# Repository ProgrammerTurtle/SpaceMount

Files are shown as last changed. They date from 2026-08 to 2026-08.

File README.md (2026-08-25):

# SpaceMount

Full_Astrophotography_Mount_2026-Aug-24_03-28-08AM-000_CustomizedView19236172479

**SpaceMount** is an open source astrophotography mount suite consisting of an automatic polar alignment unit, an equatorial mount unit, and a custom carbon fiber guider scope. 

Control is carried out by a Raspberry Pi 4B running [PINS](https://github.com/nitr57/pins) talking to an SKR Pico 3D printer mainboard sporting custom firmware. 

## Structure

SpaceMount sports a high rigidity frame made out of 1/4" lasercut aluminum, aluminum extrusions, and printed parts made of engineering-grade materials. This allows for high load capacity, high rigidity, and high accuracy. All important features to get the perfect shot.

## Drive

Gearbox_-_Lower_Stage_101_2026-Aug-24_03-46-59AM-000_CustomizedView28774878801

Mechanically, it features 3 fully custom high ratio dual stage cycloidal gearboxes powered by high torque Nema 17 stepper motors.
- One Gearbox for Azimuth
- One Gearbox for DEC
- One Gearbox for R. A.
These gearboxes are an 81:1 reduction, outputting 35Nm of torque! This allows for a high load capacity. 

The altitude axis features a custom 200:1 worm-gear-belt-drive system for resisting the toughest of conditions. 

## Polar Alignment



Mounted on the altitude axis is a camera for Polar Alignment. Utilizing Plate Solving running on the Raspberry Pi 4B, it will automatically scan the sky and align your equatorial mount with Earth's pole! No fiddling with alignment for hours. 

## Bill of Materials

The BOM can be found [here](https://docs.google.com/spreadsheets/d/1fLNac8KSqefRcGDmUohNeKdPQae2YU7nyDo7UR2l_qA/edit?usp=sharing) or attached as a .CSV in the repo.

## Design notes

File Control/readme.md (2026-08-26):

| | | |
|---|---|---|
| Top Level | [PINS](https://github.com/nitr57/pins) | Raspberry Pi |
| | | |
| Plate Solving | [ASTAP](https://www.hnsky.org/astap.htm) | Raspberry Pi |
| | | |
| Guiding | [PHD2](https://openphdguiding.org/) | Raspberry Pi |
| | | |
| Mid Level | [INDI Web Manager](https://github.com/knro/indiwebmanager) | Raspberry Pi |
| | | |
| Translation | [Custom Mount Driver](https://github.com/ProgrammerTurtle/SpaceMount/tree/main/Control/drivers) | Raspberry Pi |
| | | |
| Low Level | [Custom SKR Pico Firmware](https://github.com/ProgrammerTurtle/SpaceMount/tree/main/Control/firmware) | SKR Pico |

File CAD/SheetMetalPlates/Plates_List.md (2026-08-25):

## ALL 1/4" ALUMINUM

Polar Mount			

1	Base Arcaswiss Adapter Plate

1	Bottom Main Plate		

1	Side Plate	

1	Side Plate_Threaded	

2	Camera Mount Side Plate	

2	Shaft Plate	

1	Top Mount Plate	

---			
			
Equatorial Mount			

1	Front Plate		

1	Back Plate	

1	Bottom Plate	

2	Vixen Adapter Plate

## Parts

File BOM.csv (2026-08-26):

SpaceMount BOM |  |  | Total Estimated Cost: | $995.92
Item Name | Quantity | Cost | Use | Source | Notes
Polar Mount
Sheet Metal Plates | 9 | $142.00 | Frame | https://www.oshcut.com/ | See Plates_List
87.3mm 2040 Extrusion | 2 | $22.00 | Frame | https://www.aliexpress.us/item/3256802459096306.html? | Covers Both Lengths of 2040 - Buy 400mm and Cut to Size
52.8mm 2040 Extrusion | 2 |  | Frame
87.3mm 4040 Extrusion | 1 | $12.00 | Altitude Shaft | https://www.aliexpress.us/item/3256807986307289.html? | Buy 100mm and Cut to Size
Arcaswiss Mounting Plate and Clamp | 1 | $22.35 | Mounting | https://www.aliexpress.us/item/2251832498884091.html
RU42UUCC0 Bearing | 1 | $28.80 | Azimuth Output | https://www.aliexpress.us/item/3256808596705253.html?
61815 Bearing | 2 | $33.00 | Altitude Turret Bearing | https://www.aliexpress.us/item/3256812188522321.html?
F695 Bearing | 2 | $5.00 | Altitude Gearing Bearing | https://www.aliexpress.us/item/3256808879550935.html?
6811 Bearing | 1 | $15.00 | Azimuth Gearbox Internal Bearing | https://www.aliexpress.us/item/3256812548641570.html
6803 Bearing | 2 | $3.65 | Azimuth Gearbox Internal Bearing | https://www.aliexpress.us/item/3256808633000961.html?
5mm x 100mm Steel Pin | 1 | $11.00 | Altitude Gearing Shaft | https://www.aliexpress.us/item/3256807759794825.html?
5mm x 15mm Steel Pin | 10 | $10.00 | Azimuth Gearbox Internal Pins | https://www.aliexpress.us/item/3256807759794825.html? | Buy 2 packs
15mm M3 Standoff | 12 | $8.00 | Azimuth Gearbox Output Pin Shafts | https://www.aliexpress.us/item/3256803337647492.html? | Buy 2 packs
5mmx8mmx12mm Brass Bushing | 12 | $12.00 | Azimuth Gearbox Ouput Pin Bushings | https://www.aliexpress.us/item/3256810437400585.html? | Buy 2 packs
50t 5mm Bore Worm Gear Set | 1 | $20.50 | Altitude Gearing Gear | https://www.aliexpress.us/item/2255800299678278.html?
40T 5mm Bore 6mm Belt Pulley | 2 | $12.00 | Altitude Gearing Pulleys | https://www.aliexpress.us/item/2251832807875643.html?
450mm Length Closed Loop GT2 6mm Belt | 2 | $15.00 | Altitude Gearing Belts | https://www.aliexpress.us/item/3256812034723597.html?
Angeleyes Small Vixen Clamp | 1 | $34.00 | Altitude External Mounting | https://www.aliexpress.us/item/3256807005155740.html?
M6x10mm Socket Head Bolts | 4 | $3 | Assembly | https://www.aliexpress.us/item/3256802134660814.html
M5x100mm Socket Head Bolts | 7 | $10 | Assembly | https://www.amazon.com/Joamang-M5-0-8-Socket-Stainless-Threaded/dp/B0DPHTLG5H/
M5x10mm Socket Head Bolts | 9 | $2 | Assembly | https://www.aliexpress.us/item/3256802134660814.html
M5x16mm Socket Head Bolts | 36 | $10 | Assembly | https://www.amazon.com/M5-0-8-Socket-Screws-Stainless-Thread/dp/B07PXL8DGH
M5x25mm Socket Head Bolts | 21 | $7 | Assembly | https://www.aliexpress.us/item/3256802134660814.html? | Buy 3 packs
M5x20mm Socket Head Bolts | 2 | $2.50 | Assembly | https://www.aliexpress.us/item/3256802134660814.html?
M5 Heat Set Inserts Long (M5xL6xOD7) | 4 |  | Assembly | https://www.aliexpress.us/item/3256805885174058.html?
M4x75mm Socket Head Bolts | 10 | $7.00 | Assembly | https://www.aliexpress.us/item/3256808167502621.html
M4x16mm Socket Head Bolt | 4 |  | Assembly | https://www.aliexpress.us/item/3256802134660814.html
M4 Hex Locknuts | 10 | $2.00 | Assembly | https://www.aliexpress.us/item/2251832801119212.html?
M3x16mm Countersunk Head Bolts | 12 | $2.50 | Assembly | https://www.aliexpress.us/item/2251832781782755.html?
M3x40mm Socket Head Bolts | 4 |  | Assembly | https://www.aliexpress.us/item/3256802134660814.html
M3x25mm Socket Head Bolts | 6 | $3.50 | Assembly | https://www.aliexpress.us/item/3256802134660814.html
M3x20mm Socket Head Bolts | 6 | $3.20 | Assembly | https://www.aliexpress.us/item/3256802134660814.html
M3x12mm Socket Head Bolts | 4 | $3.00 | Assembly | https://www.aliexpress.us/item/3256802134660814.html
M3 Heat Set Inserts Long (M3xL6xOD4) | 9 |  | Assembly | https://www.aliexpress.us/item/3256805885174058.html?
M2x12mm Socket Head Bolts | 4 | $1.82 | Assembly | https://www.aliexpress.us/item/3256802134660814.html
M2x5mm Socket Head Bolts | 4 | $2 | Assembly | https://www.aliexpress.us/item/3256802134660814.html
5mm Bore Shaft Collar | 1 | $2 | Azimuth Gearbox Cam Shaft Attachment | https://www.aliexpress.us/item/3256810520261418.html?
2004s1 Nema 17 Stepper Motor | 2 | $28 | Drive Motors | https://www.aliexpress.us/item/3256806039037773.html? | Use Any with Decent Torque
Equatorial Mount
Sheet Metal Plates | 5 | $88.00 | Frame | https://www.oshcut.com/
87.3mm 2040 Extrusion | 4 | $22.00 | Frame | https://www.aliexpress.us/item/3256802459096306.html | Buy 400mm and Cut to Size
Angeleyes Small Vixen Clamp | 1 | $34.00 | Altitude External Mounting | https://www.aliexpress.us/item/3256807005155740.html?
Angeleyes 80mm Vixen Rail | 1 | $13.00 | Mounting | https://www.aliexpress.us/item/3256808818951030.html?
5mm x 15mm Steel Pin | 20 | $15.00 | R.A. and Dec Gearbox Internal Pins | https://www.aliexpress.us/item/3256807759794825.html? | Buy 4 packs
15mm M3 Standoff | 24 | $12.00 | R.A and Dec Gearbox Output Pin Shafts | https://www.aliexpress.us/item/3256803337647492.html? | Buy 3 packs
5mmx8mmx12mm Brass Bushing | 24 | $14.00 | R.A. and Dec Gearbox Ouput Pin Bushings | https://www.aliexpress.us/item/3256810437400585.html? | Buy 3 packs
RU42UUCC0 Bearing | 2 | $60.00 | R.A. and Dec Main Bearings | https://www.aliexpress.us/item/3256808596705253.html?
6811 Bearing | 2 | $33.00 | R.A. and Dec Gearbox Internal Bearings | https://www.aliexpress.us/item/3256812548641570.html
6803 Bearing | 4 | $7.80 | R.A. and Dec Gearbox Internal Bearing | https://www.aliexpress.us/item/3256808633000961.html?
M6x12 Socket Head Bolt | 3 | $3.00 | Assembly | https://www.aliexpress.us/item/3256802134660814.html
M6x10 Socket Head Bolt | 4 | $3.00 | Assembly | https://www.aliexpress.us/item/3256802134660814.html
M5x16mm Socket Head Bolt | 16 | $5.00 | Assembly | https://www.aliexpress.us/item/3256802134660814.html | Buy 2 packs
M5x10mm Socket Head Bolt | 6 | $2.00 | Assembly | https://www.aliexpress.us/item/3256802134660814.html
M5 T Nuts | 6 | $6.20 | Assembly | https://www.aliexpress.us/item/2251832618848960.html? | Use extra to attach any mods/additions to the existing extrusions.
M4x75mm Socket Head Bolt | 20 | $11.00 | Assembly | https://www.aliexpress.us/item/3256808167502621.html | Buy 2 packs
M4 Hex Locknuts | 20 | $4.00 | Assembly | https://www.aliexpress.us/item/2251832801119212.html | Buy 2 packs
M3x16mm Countersunk Head Bolts | 24 |  | Assembly | https://www.aliexpress.us/item/2251832781782755.html? | Excess from Polar Mount
M3x25mm Socket Head Bolts | 12 |  | Assembly | https://www.aliexpress.us/item/3256802134660814.html | Excess from Polar Mount
M3x20mm Socket Head Bolts | 12 |  | Assembly | https://www.aliexpress.us/item/3256802134660814.html | Excess from Polar Mount
M3 Heat Set Inserts Long (M3xL6xOD4) | 9 |  | Assembly | https://www.aliexpress.us/item/3256805885174058.html?
5mm Bore Shaft Collar | 2 |  | R.A. and Dec Gearbox Cam Shaft Attachment | https://www.aliexpress.us/item/3256810520261418.html? | Excess from Polar Mount
2004s1 Nema 17 Stepper Motor | 2 | $28 | R.A. and Dec Drive Motors | https://www.aliexpress.us/item/3256806039037773.html? | Use Any with Decent Torque
Guider Scope
IMX290 Sensor | 1 | $53.00 | Guide Scope Sensor | https://shop.openastrotech.com/products/openastroguider-hardware-only?variant=39254160113851
182mm Focal Length 50mm Lens | 1 | $20.00 | Guide Scope Optics | https://shop.openastrotech.com/products/openastroguider-hardware-only?variant=39254160081083
M5x20mm Socket Head Screw | 1 |  | Assembly | https://www.aliexpress.us/item/3256802134660814.html? | Excess from Polar Mount
M5 Hex Nut | 1 |  | Assembly | https://www.aliexpress.us/item/3256811960981887.html
M5 Heat Set Inserts Long (M5xL6xOD7) | 4 |  | Assembly | https://www.aliexpress.us/item/3256805885174058.html? | Excess from Polar Mount
M3x10mm Socket Head Bolt | 4 |  | Assembly | https://www.aliexpress.us/item/3256802134660814.html
M2.5x10mm Socket Head Bolt | 4 |  | Assembly | https://www.aliexpress.us/item/3256802134660814.html
54mm ID Carbon Fiber tube | 1 |  | Structure | Your Choice | Source from anywhere, must be 54mm ID. I am winding it myself.
Electronics
SKR Pico Mainboard | 1 | $30.00 | Control | https://www.aliexpress.us/item/3256806852052563.html?
Raspberry Pi 4b | 1 |  | Control | https://www.raspberrypi.com/products/raspberry-pi-4-model-b/ | Can substitute with many options including other Pis, mini PCs, a laptop, etc.
Raspberry Pi Camera | 1 | $6.00 | Polar Alignment Camera | https://www.aliexpress.us/item/2251832482194239.html? | Can substitute with many other options.
CSI to HDMI Converter Pair | 1 | $14.00 | Connecting Polar Alignment Camera | https://www.amazon.com/Arducam-Extension-Module-Raspberry-Specific/dp/B06XDNBM63/ | Optional but highly recommended as ribbon cable is very fragile.
24v 3A Power Supply | 1 | $11.00 | Powering SKR Pico | https://www.aliexpress.us/item/3256807053145543.html? | Can be substituted for a more standard power supply, or for a 12v power supply, with varying performance.
6015 Fan | 1 | $5.00 | Cooling Electronic | https://www.aliexpress.us/item/3256808462626568.html? | I am using 5v and controlling it with the pi. You can also use 12/24 and control it off the Pico.
Misc.

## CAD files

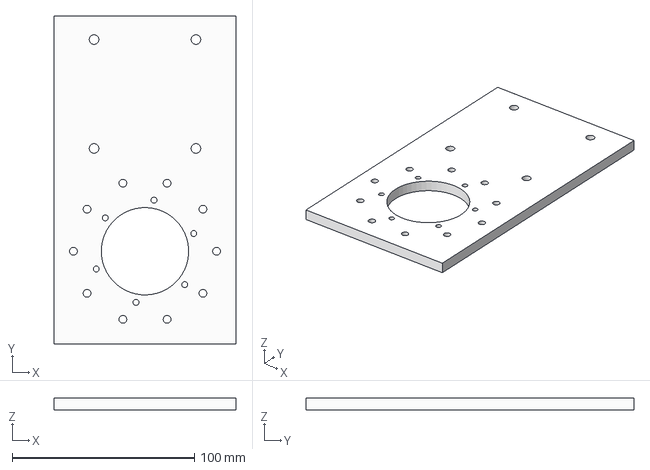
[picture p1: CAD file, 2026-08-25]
CAD/SheetMetalPlates/PolarMount/Bottom Main Plate.step
100.0 x 180.0 x 6.35 mm

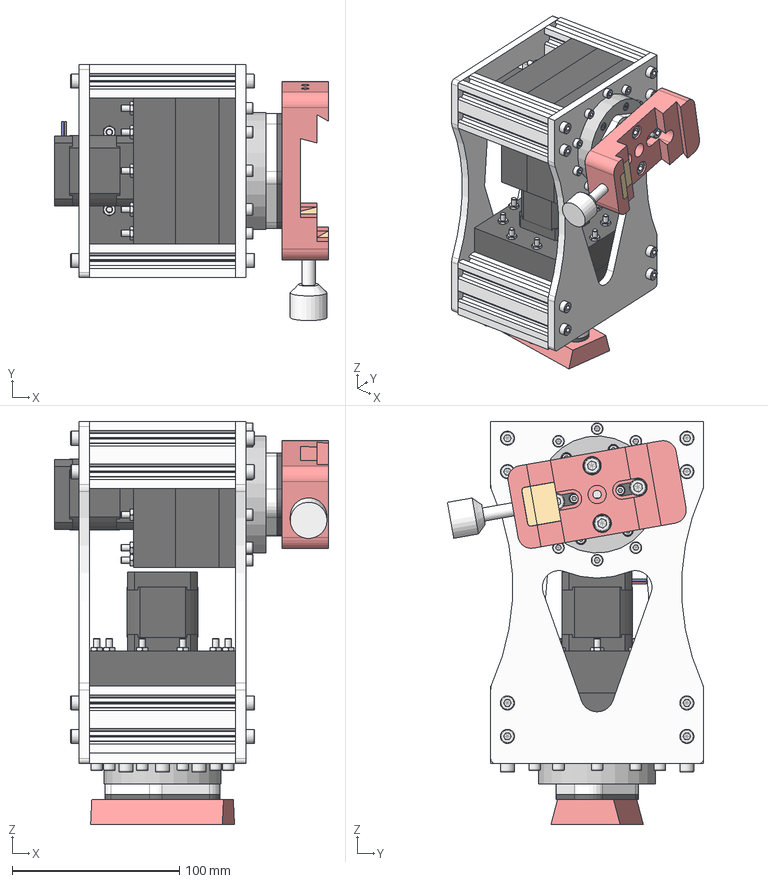
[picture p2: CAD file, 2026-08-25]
CAD/EquatorialMount/SpaceMount Equatorial Mount.step
164.1 x 153.2 x 241.0 mm
NEMA17_17HS19-2004S1_Stepperonline x 2
Cam_1 x 2
Shaft Collar x 2
5972K278_Steel Ball Bearing x 8
Upper
Lower
Brass Bushing 5x8x12 x 12
M3 Standoff 15mm x 12
ISO 10642 - M3 x 16 Steel 8.8 Plain x 24
6656K234_Steel Ball Bearing x 2
Cycloidal Gear - Small x 8
Bottom 1mm Spacer
Mid 1mm Spacer x 4
5mm Pin 15mm x 20
Lower Housing
94180A333_NO THREADS_Brass Tapered Heat-Set Inserts for Plastic x 6
4mm Mid Spacer
External Output Shaft
Cam
RU42UUCCO Slew Bearing x 2
Upper Housing
Mid Housing
ISO 4762 - M3 x 20 Steel 4.6 Plain x 24
ISO 4762 - M4 x 75 Steel 4.6 Plain x 20
ISO 4035 - M4 Steel 6 Plain x 20
Lower (1)
Upper (1)
Brass Bushing 5x8x12 (1) x 12
M3 Standoff 15mm (1) x 12
Bottom 1mm Spacer (1)
Mid 1mm Spacer (1) x 4
5mm Pin 15mm (1) x 20
Lower Housing (1)
94180A333_NO THREADS_Brass Tapered Heat-Set Inserts for Plastic_1 x 6
4mm Mid Spacer (1)
External Output Shaft (1)
Cam (1)
Upper Housing (1)
Mid Housing (1)
2040 Aluminim profile x 4
Back Panel
Front Plate
Bottom Plate
Bottom Output Plate x 2
ISO 4762 - M5 x 16 Steel 4.6 Plain x 16
ISO 4762 - M5 x 10 Steel 4.6 Plain x 6
Vixen Adapter Spacer x 2
Vixen Adapter Plate x 2
Clamp_S
ISO 4762 - M3 x 10 Steel 4.6 Plain x 12
ISO 4762 - M6 x 12 Steel 4.6 Plain x 7
80mm Vixen Dovetail Bar

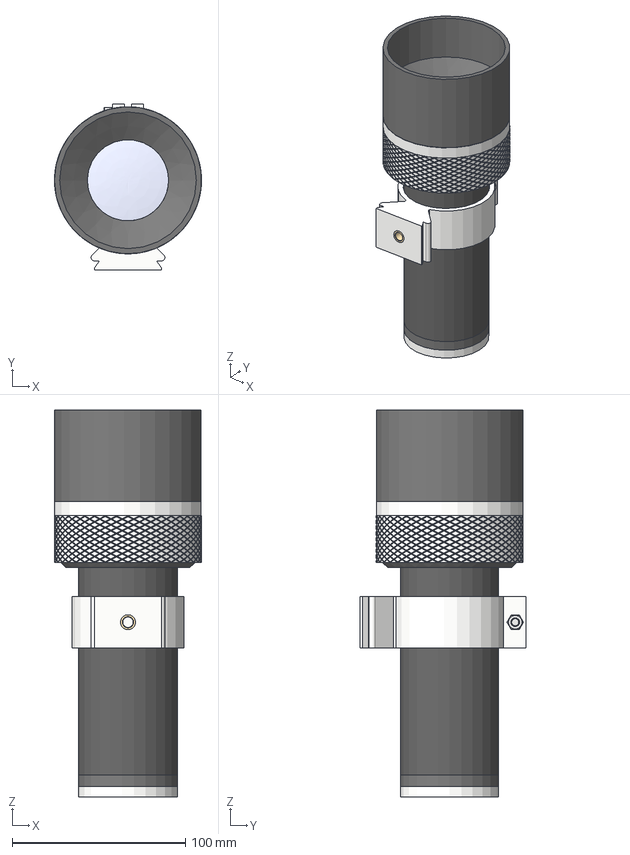
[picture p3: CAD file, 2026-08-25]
CAD/GuideScope/SpaceMount Guide Scope.step
85.0 x 95.7 x 223.7 mm
50.183 Linse
IMX290
Camera Holder
Camera Cover
Carbon Fiber Tube
Dew Shield
97163A157_NO THREADS_18-8 Stainless Steel Tapered Heat-Set Insert for Plastic
ISO 4762 - M5 x 20 Steel 4.6 Plain
ISO 4035 - M5 Steel 6 Plain
Base Flange/Thread
Knob
Focus Slider
Retainer Ring
Lens Holder/Dew Cover

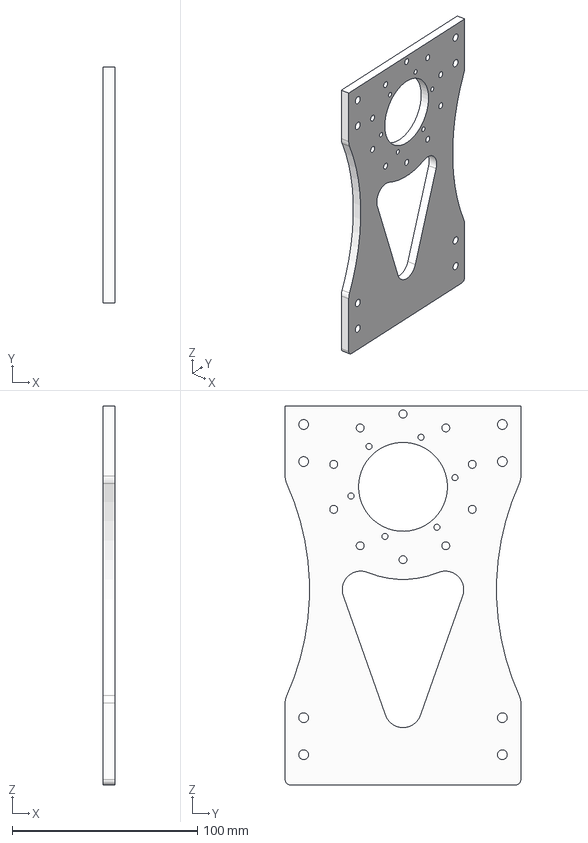
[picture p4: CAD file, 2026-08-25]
CAD/SheetMetalPlates/EquatorialMount/Front Plate.step
6.35 x 127.3 x 204.7 mm

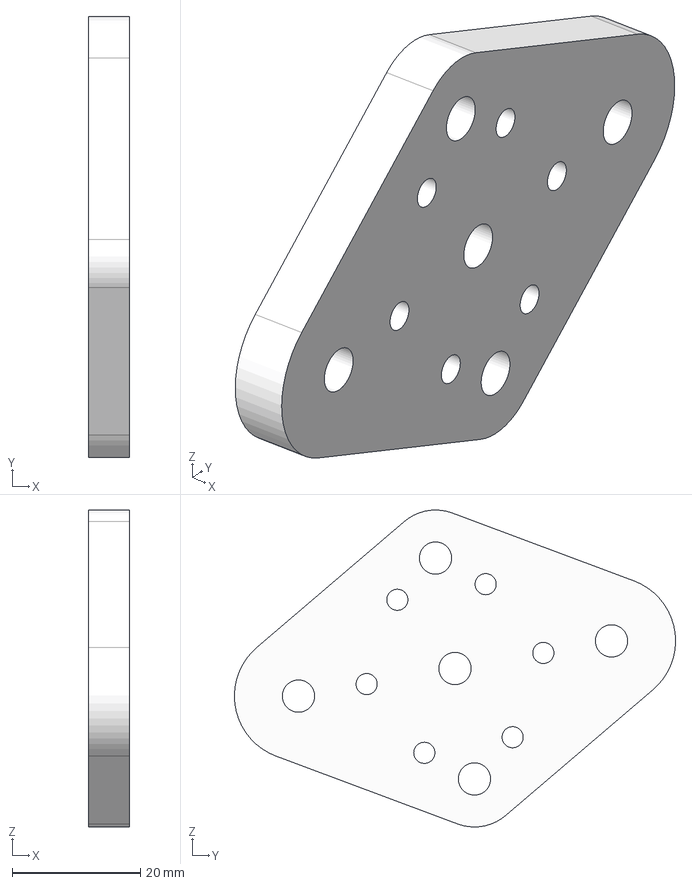
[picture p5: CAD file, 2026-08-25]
CAD/SheetMetalPlates/EquatorialMount/Vixen Adapter Plate.step
6.35 x 68.8 x 49.5 mm

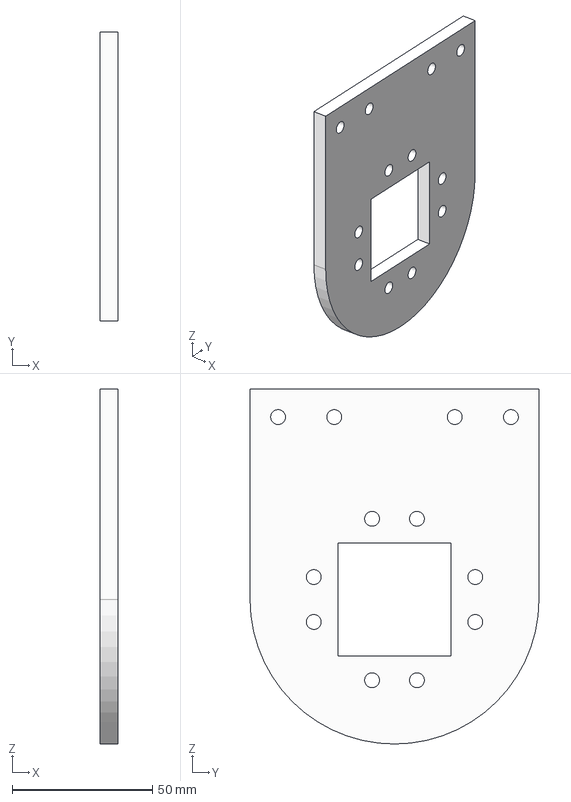
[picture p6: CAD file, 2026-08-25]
CAD/SheetMetalPlates/PolarMount/Camera Mount Side Plate.step
6.35 x 103.0 x 126.5 mm

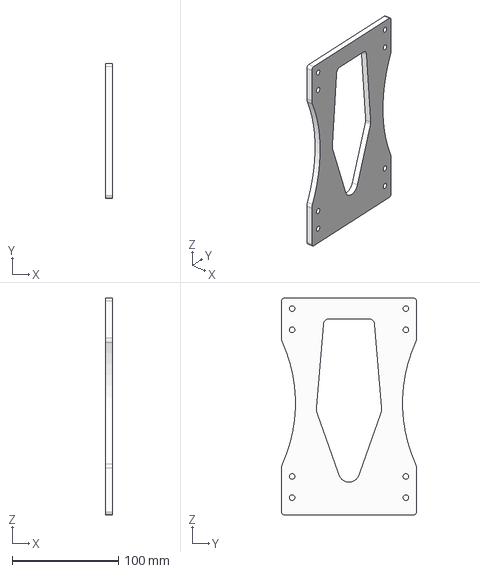
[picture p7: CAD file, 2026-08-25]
CAD/SheetMetalPlates/EquatorialMount/Back Plate.step
6.35 x 127.3 x 204.7 mm

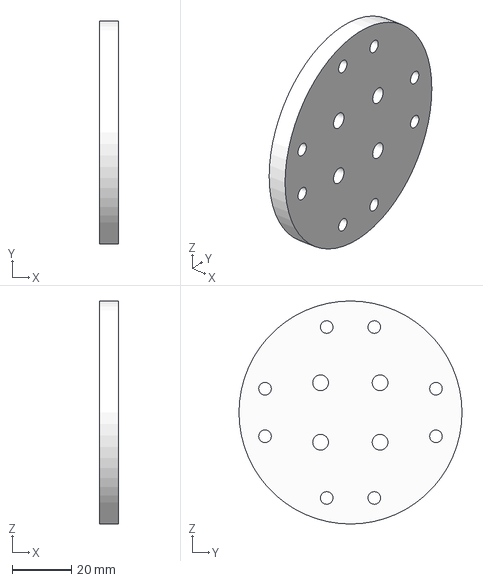
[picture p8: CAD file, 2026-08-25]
CAD/SheetMetalPlates/PolarMount/Shaft Plate.step
6.35 x 75.0 x 75.0 mm

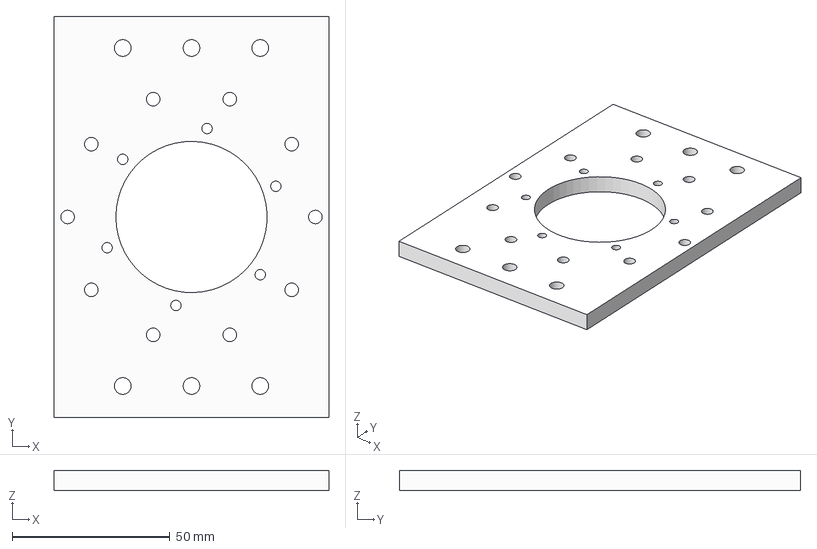
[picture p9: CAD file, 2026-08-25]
CAD/SheetMetalPlates/EquatorialMount/Bottom Plate.step
87.3 x 127.3 x 6.35 mm

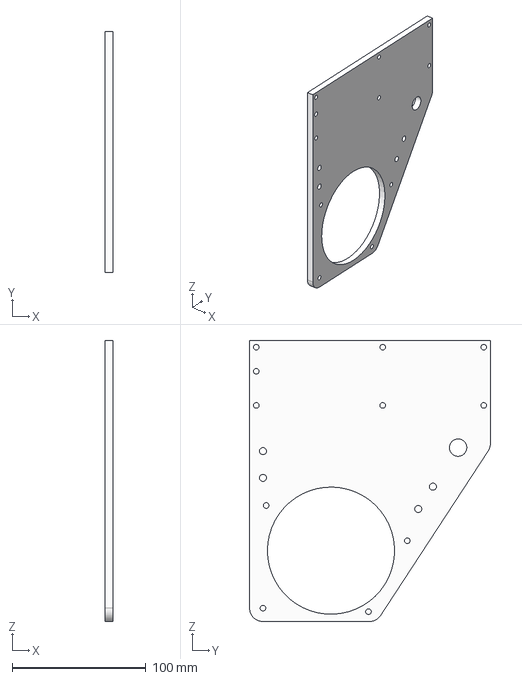
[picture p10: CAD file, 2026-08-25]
CAD/SheetMetalPlates/PolarMount/Side Plate_Threaded.step
6.35 x 180.0 x 210.0 mm

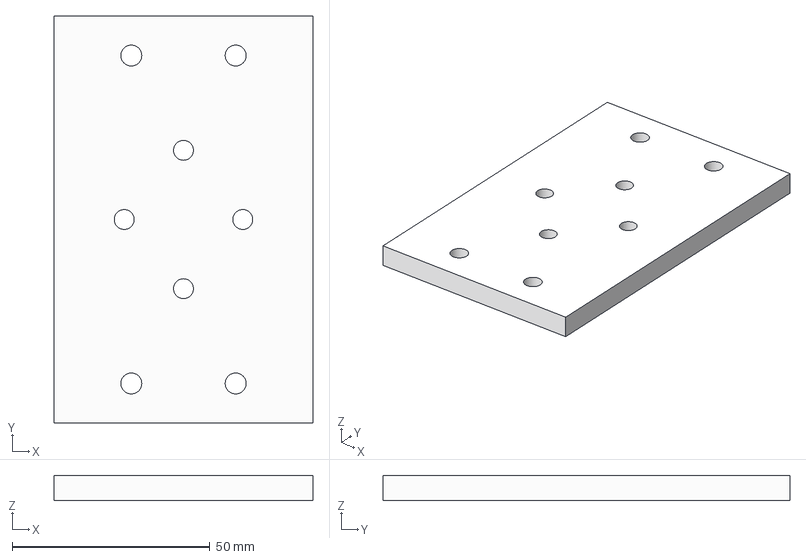
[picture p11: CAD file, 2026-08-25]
CAD/SheetMetalPlates/PolarMount/Top Mount Plate.step
65.5 x 103.0 x 6.35 mm

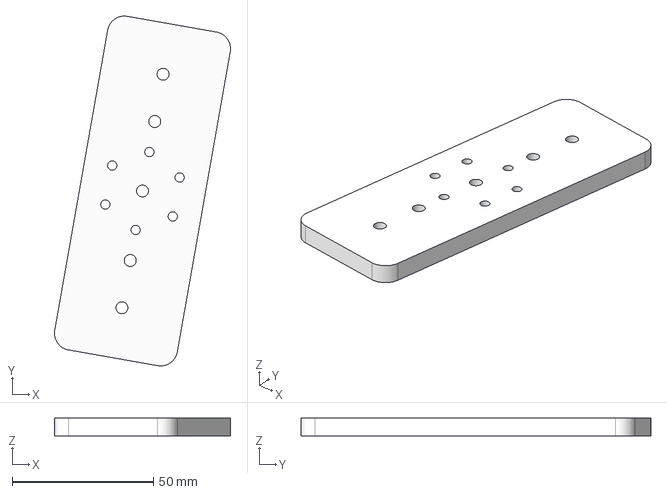
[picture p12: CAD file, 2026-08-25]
CAD/SheetMetalPlates/PolarMount/Base Arcaswiss Adapter Plate.step
62.3 x 123.9 x 6.35 mm

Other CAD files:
CAD/SheetMetalPlates/PolarMount/Side Plate.step
CAD/EquatorialMount/SpaceMount Equatorial Mount.f3z
CAD/GuideScope/SpaceMount Guide Scope.f3z

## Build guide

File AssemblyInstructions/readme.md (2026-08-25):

Assembly instructions for all three parts of this project.

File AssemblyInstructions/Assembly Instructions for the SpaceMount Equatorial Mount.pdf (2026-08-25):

## Assembly Instructions for the SpaceMount Equatorial Mount

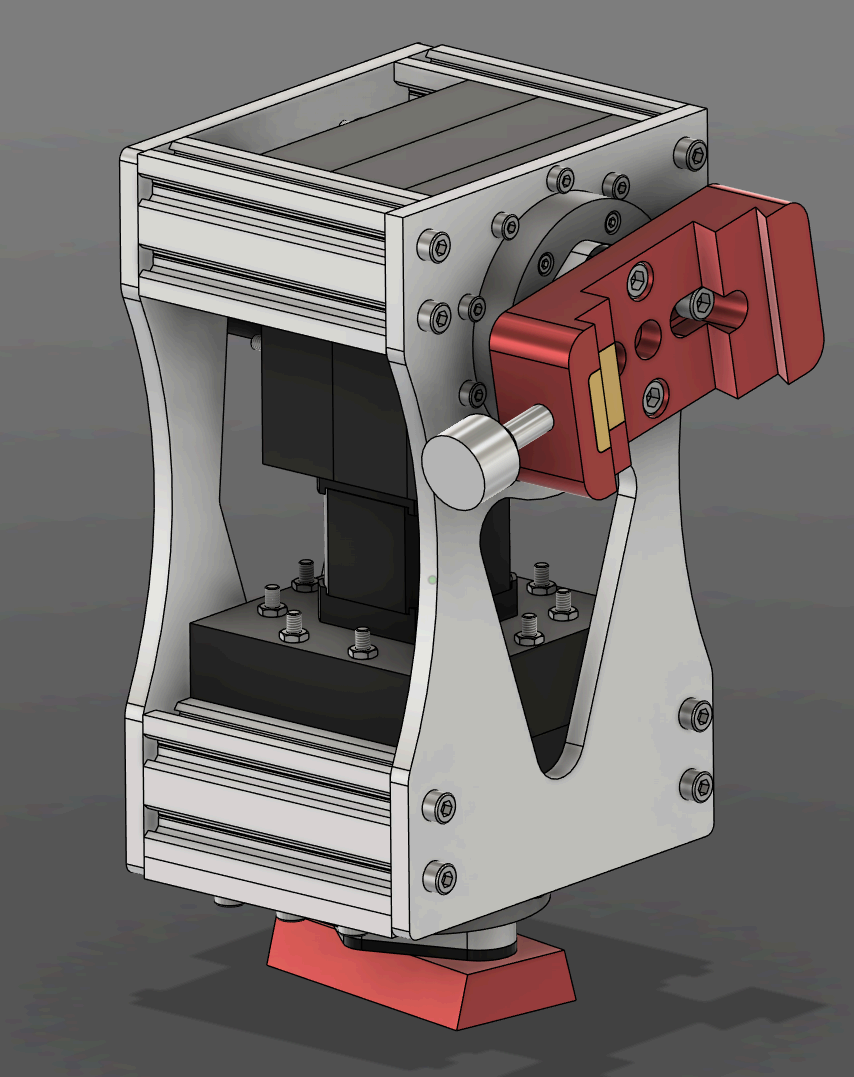
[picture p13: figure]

1 Parker Rupe

## Preface

This is the assembly guide for my motorized equatorial mount that is part of my SpaceMount (https://github.com/ProgrammerTurtle/SpaceMount) project. It is certainly not error free, but it is written to the best of my abilities. Always refer to the master CAD assembly provided in the Github Repository for confirmation of assembly. Best of Luck!!

Note: Unless otherwise stated, assume screws are Socket Head Cap Screws (SHCS).

## Part 1: The R.A. and Dec Cycloidal Gearboxes

Note: You may use the M4x75 bolts inserted from the rear to hold the gearbox together during assembly, but keep in mind they must ultimately be inserted from the front to be assembleable.

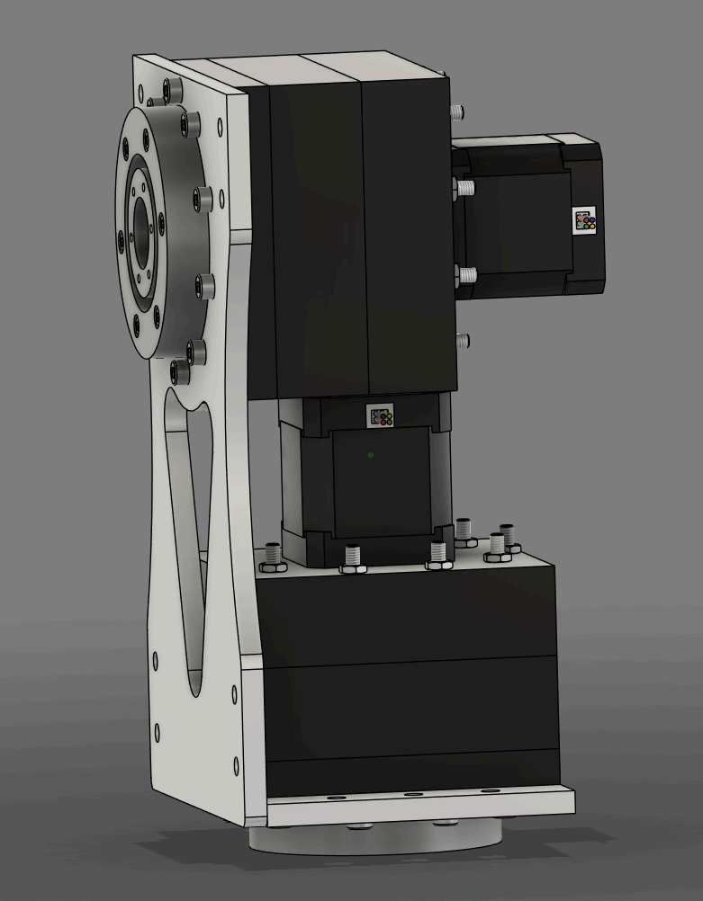
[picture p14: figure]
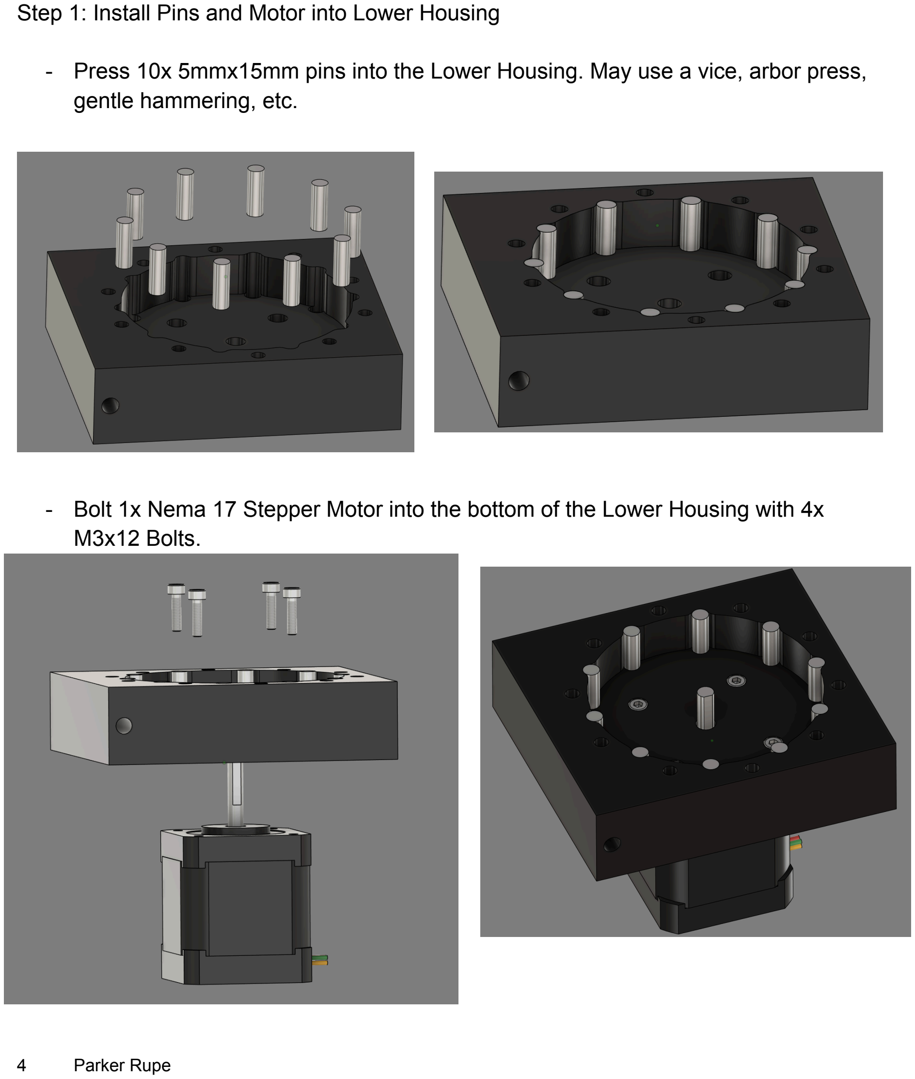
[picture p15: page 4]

Step 1: Install Pins and Motor into Lower Housing
- Press 10x 5mmx15mm pins into the Lower Housing. May use a vice, arbor press, gentle hammering, etc.
- Bolt 1x Nema 17 Stepper Motor into the bottom of the Lower Housing with 4x M3x12 Bolts.

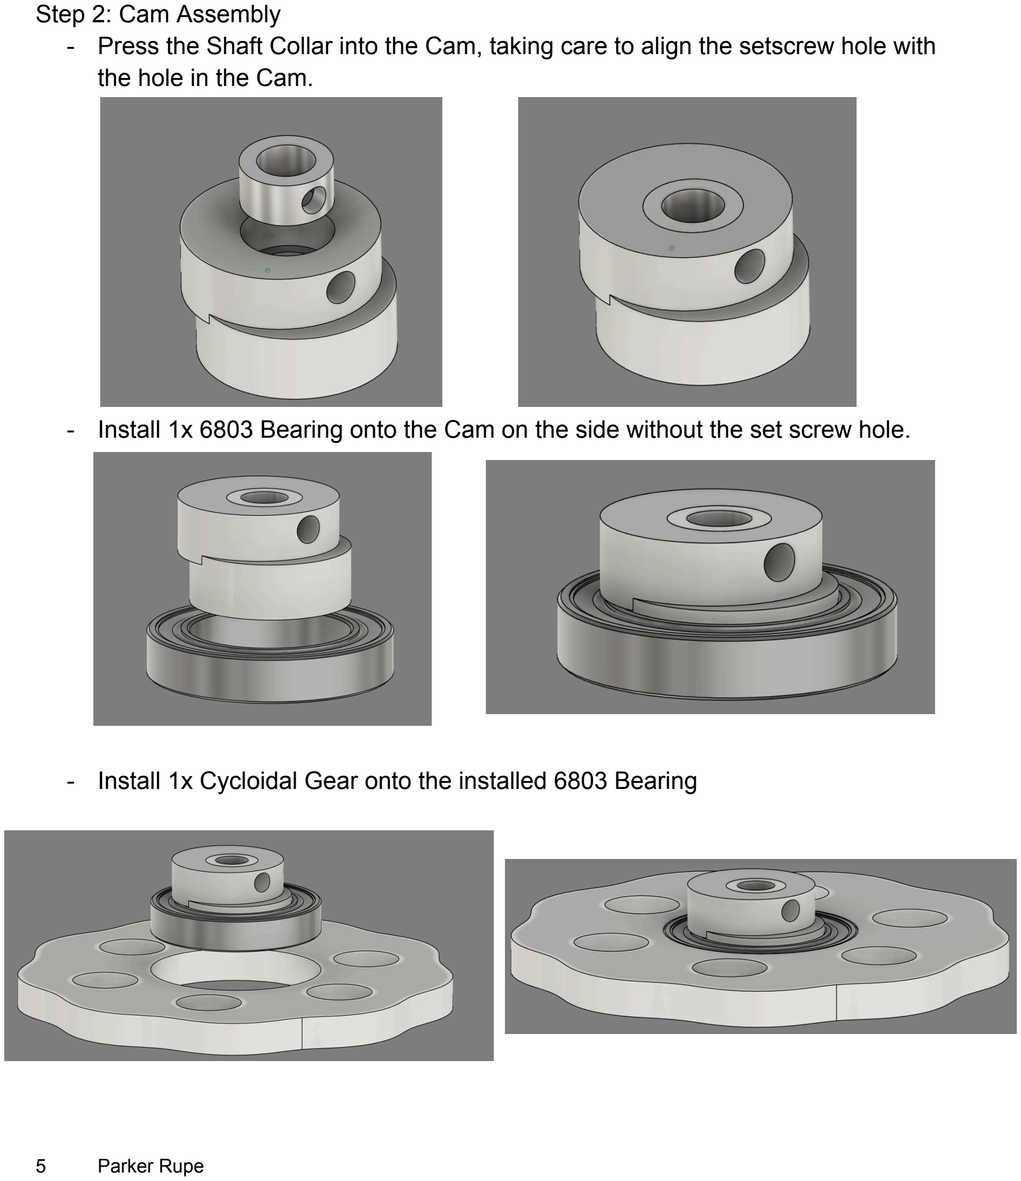
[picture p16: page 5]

Step 2: Cam Assembly
- Press the Shaft Collar into the Cam, taking care to align the setscrew hole with the hole in the Cam.
- Install 1x 6803 Bearing onto the Cam on the side without the set screw hole.
- Install 1x Cycloidal Gear onto the installed 6803 Bearing

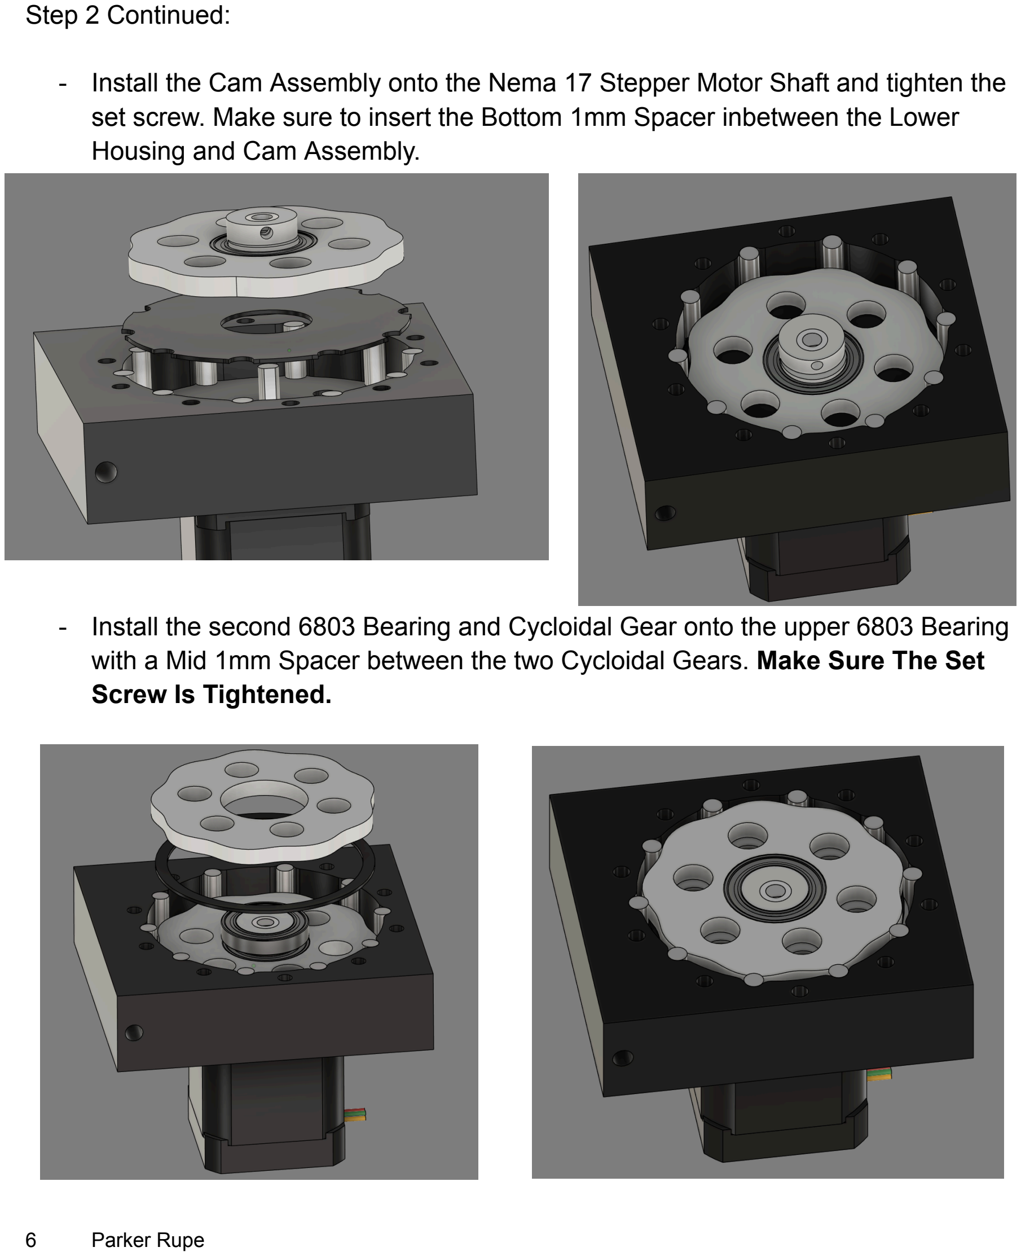
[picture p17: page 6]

Step 2 Continued:
- Install the Cam Assembly onto the Nema 17 Stepper Motor Shaft and tighten the set screw. Make sure to insert the Bottom 1mm Spacer inbetween the Lower Housing and Cam Assembly.
- Install the second 6803 Bearing and Cycloidal Gear onto the upper 6803 Bearing with a Mid 1mm Spacer between the two Cycloidal Gears. Make Sure The Set Screw Is Tightened.

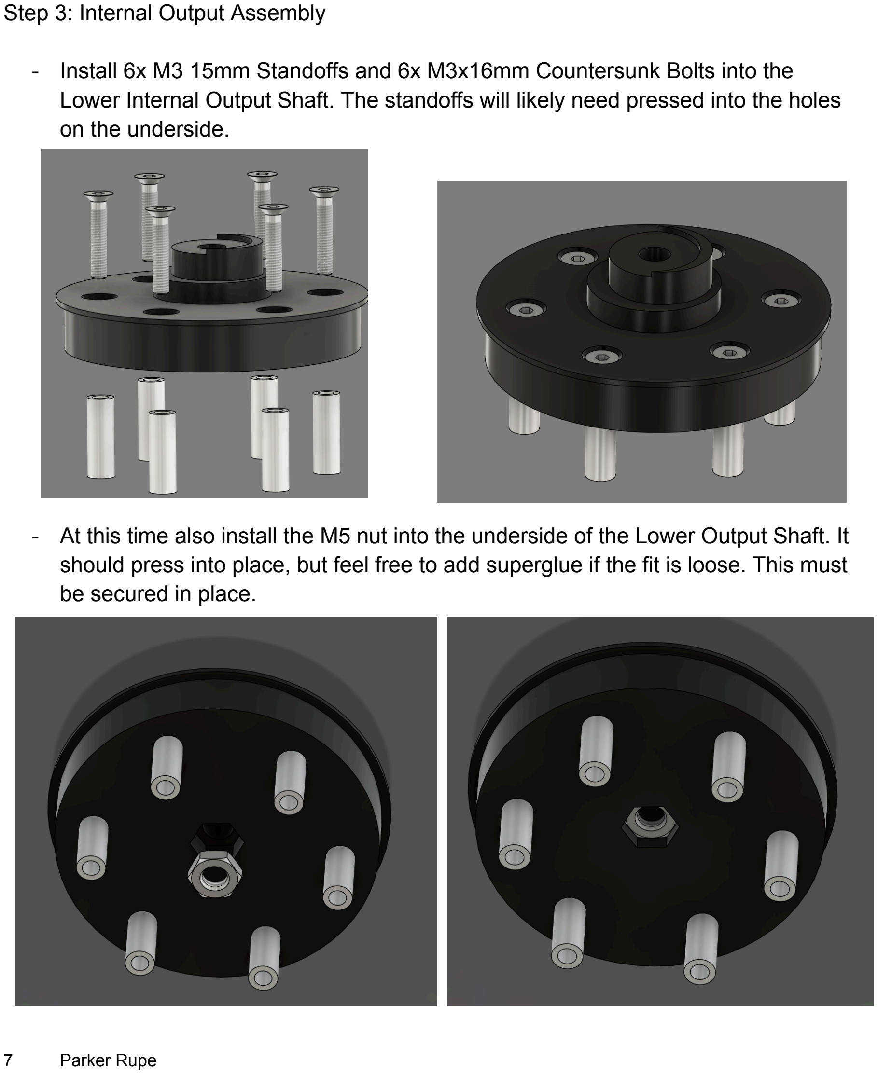
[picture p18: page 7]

Step 3: Internal Output Assembly
- Install 6x M3 15mm Standoffs and 6x M3x16mm Countersunk Bolts into the Lower Internal Output Shaft. The standoffs will likely need pressed into the holes on the underside.
- At this time also install the M5 nut into the underside of the Lower Output Shaft. It should press into place, but feel free to add superglue if the fit is loose. This must be secured in place.

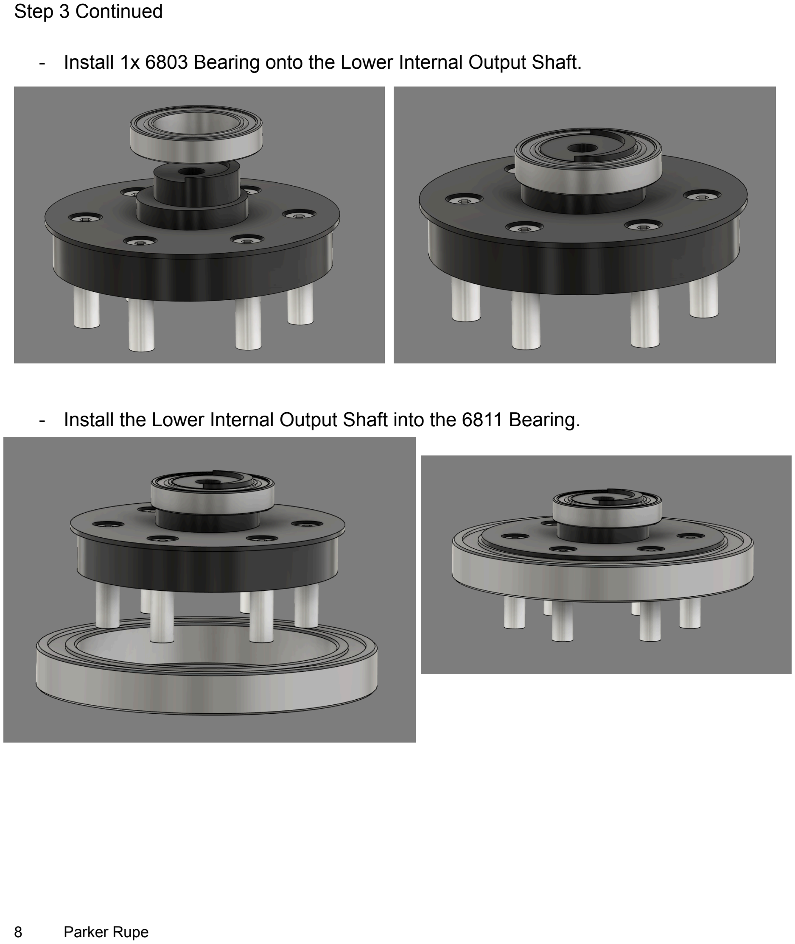
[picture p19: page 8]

Step 3 Continued
- Install 1x 6803 Bearing onto the Lower Internal Output Shaft.
- Install the Lower Internal Output Shaft into the 6811 Bearing.

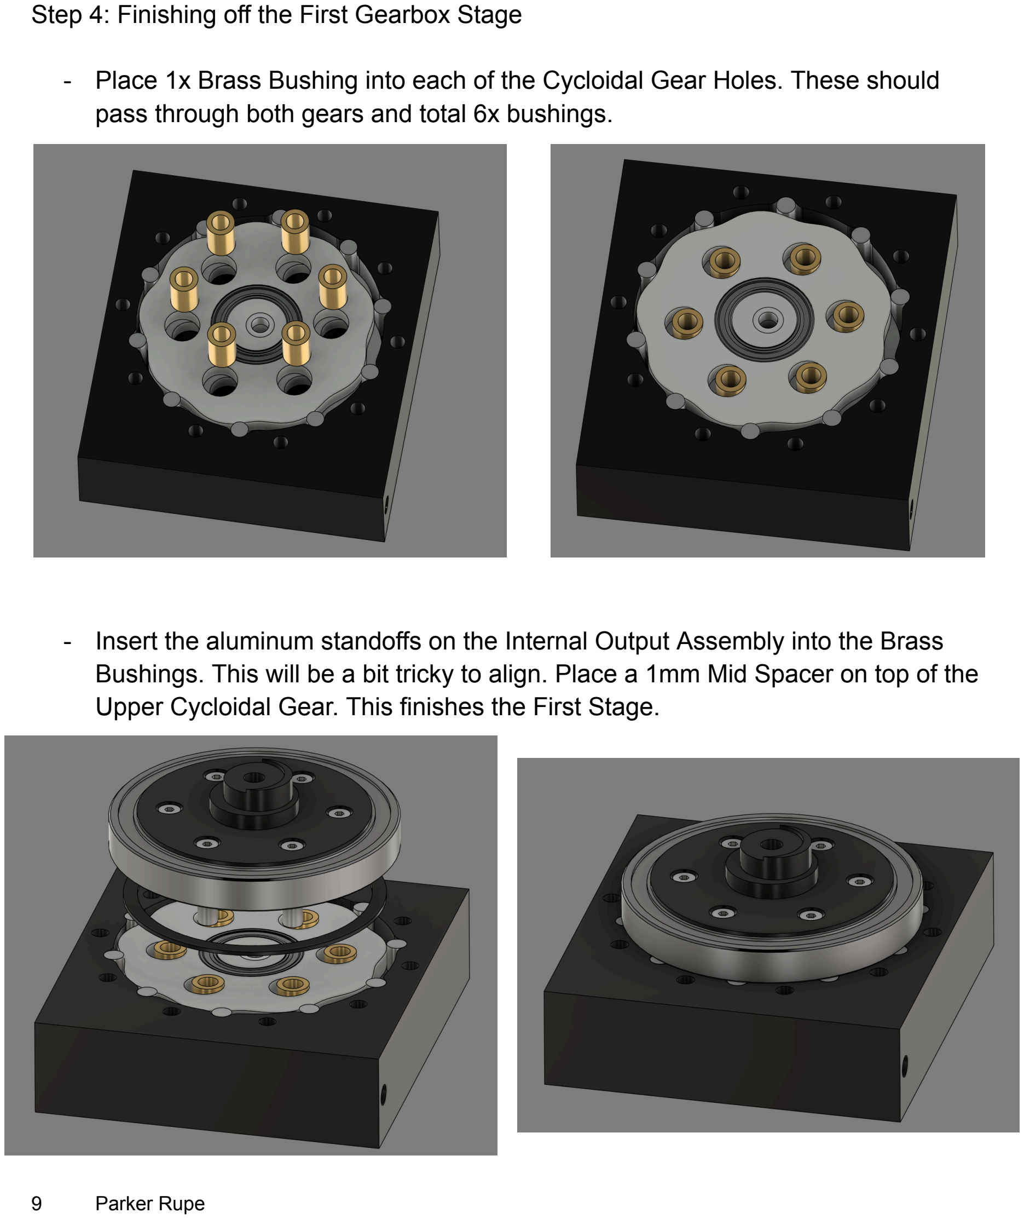
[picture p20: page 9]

Step 4: Finishing off the First Gearbox Stage
- Place 1x Brass Bushing into each of the Cycloidal Gear Holes. These should pass through both gears and total 6x bushings.
- Insert the aluminum standoffs on the Internal Output Assembly into the Brass Bushings. This will be a bit tricky to align. Place a 1mm Mid Spacer on top of the Upper Cycloidal Gear. This finishes the First Stage.

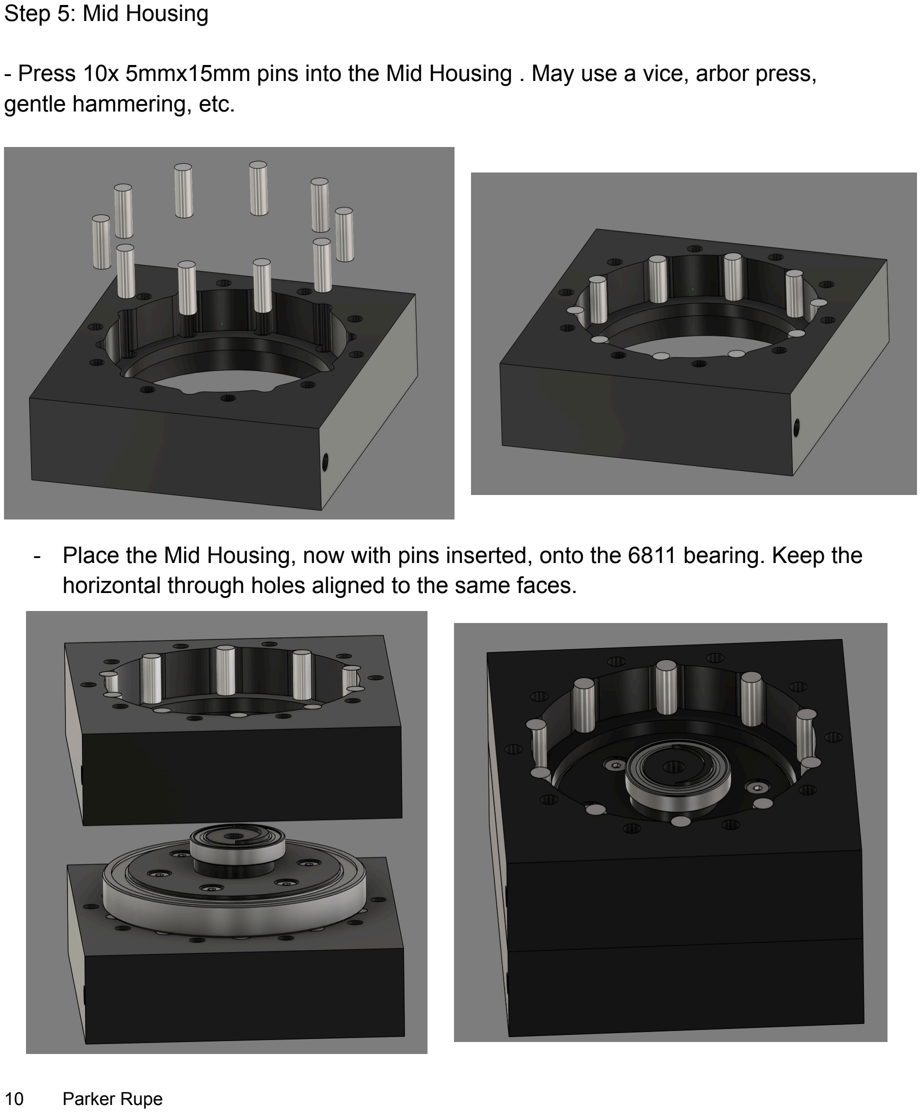
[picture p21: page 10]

Step 5: Mid Housing
- Press 10x 5mmx15mm pins into the Mid Housing . May use a vice, arbor press, gentle hammering, etc.
- Place the Mid Housing, now with pins inserted, onto the 6811 bearing. Keep the horizontal through holes aligned to the same faces.

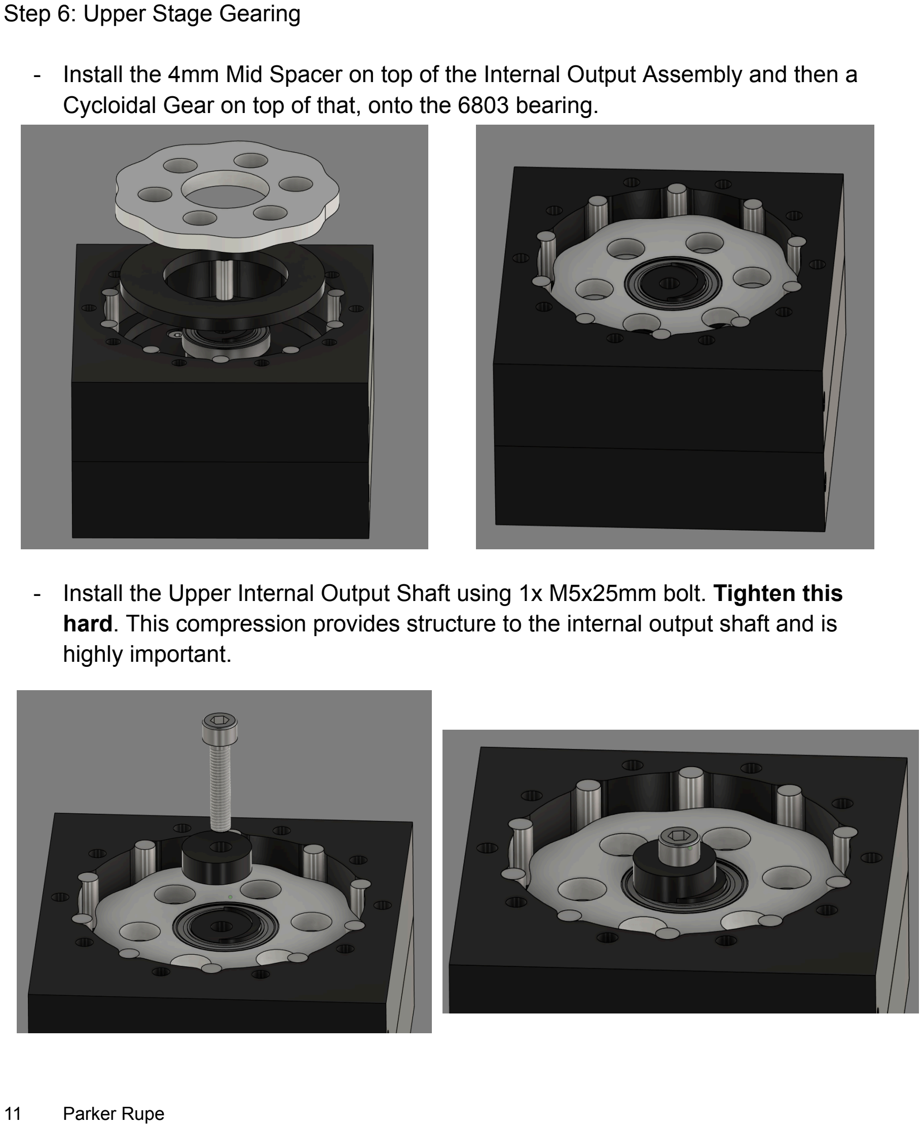
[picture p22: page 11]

Step 6: Upper Stage Gearing
- Install the 4mm Mid Spacer on top of the Internal Output Assembly and then a Cycloidal Gear on top of that, onto the 6803 bearing.
- Install the Upper Internal Output Shaft using 1x M5x25mm bolt. Tighten this hard. This compression provides structure to the internal output shaft and is highly important.

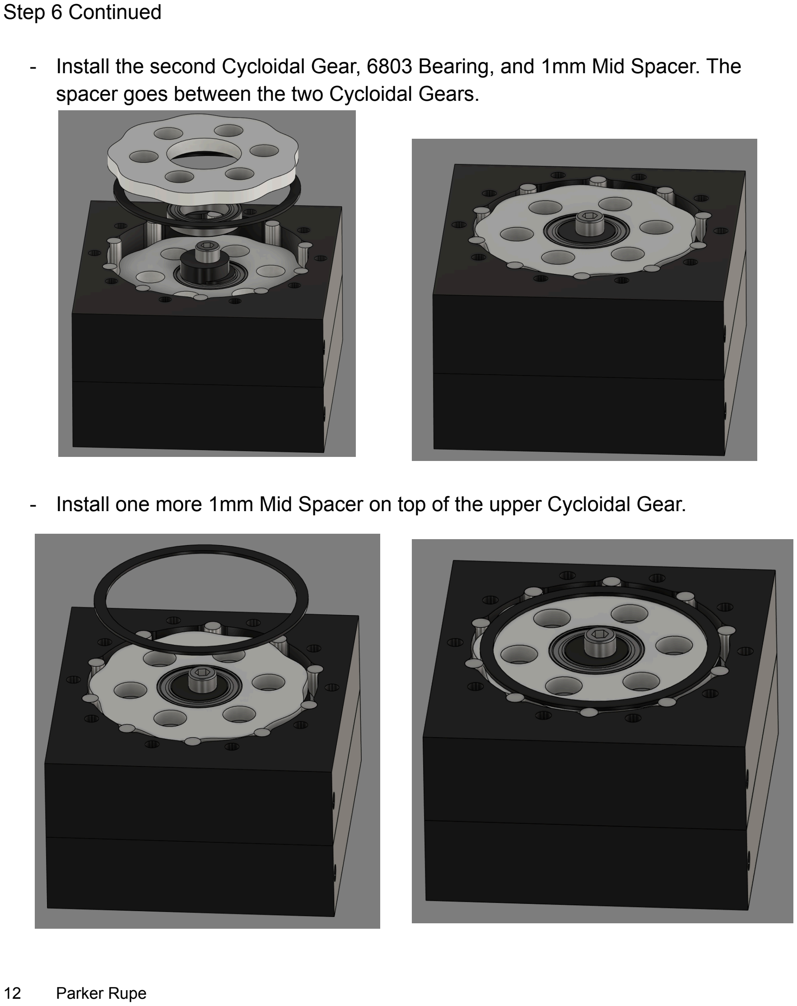
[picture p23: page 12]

Step 6 Continued
- Install the second Cycloidal Gear, 6803 Bearing, and 1mm Mid Spacer. The spacer goes between the two Cycloidal Gears.
- Install one more 1mm Mid Spacer on top of the upper Cycloidal Gear.

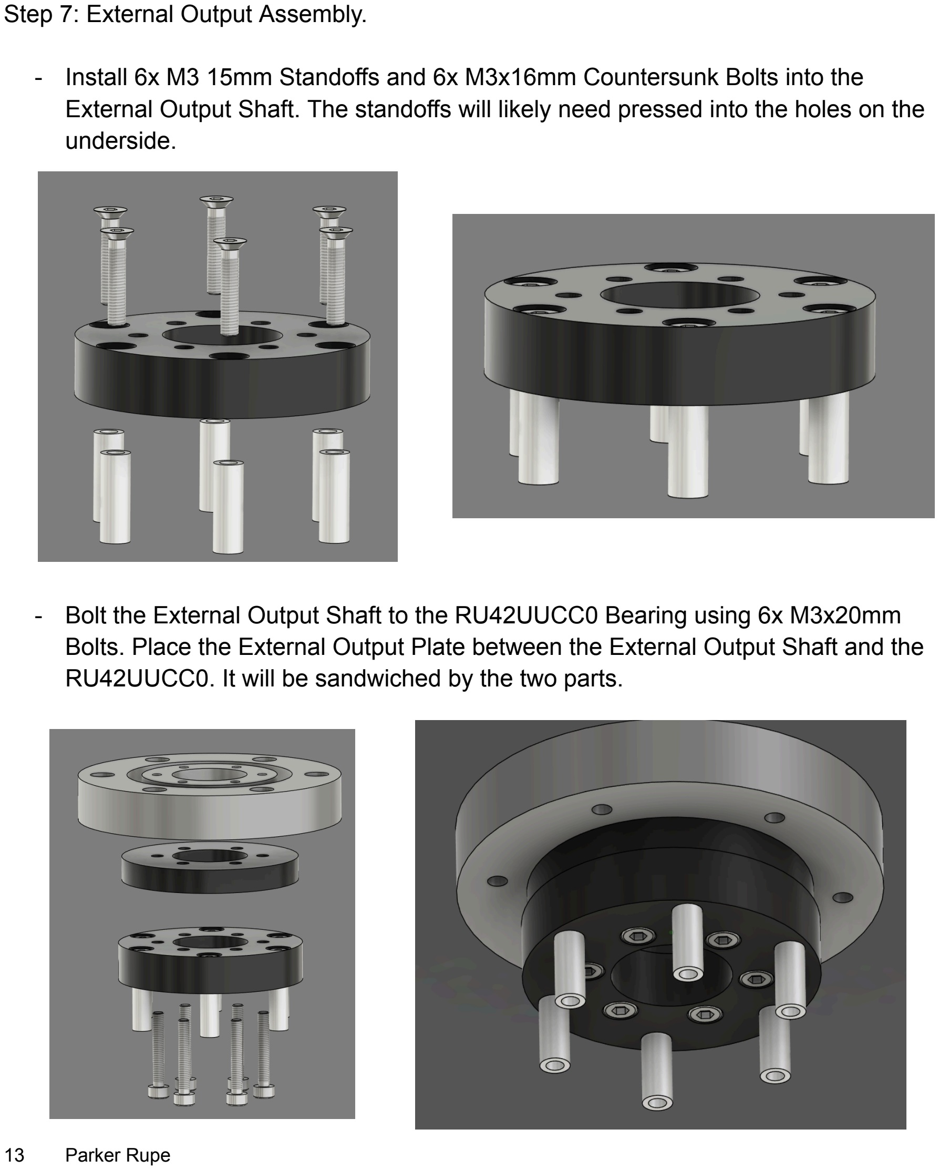
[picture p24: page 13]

Step 7: External Output Assembly.
- Install 6x M3 15mm Standoffs and 6x M3x16mm Countersunk Bolts into the External Output Shaft. The standoffs will likely need pressed into the holes on the underside.
- Bolt the External Output Shaft to the RU42UUCC0 Bearing using 6x M3x20mm Bolts. Place the External Output Plate between the External Output Shaft and the RU42UUCC0. It will be sandwiched by the two parts.

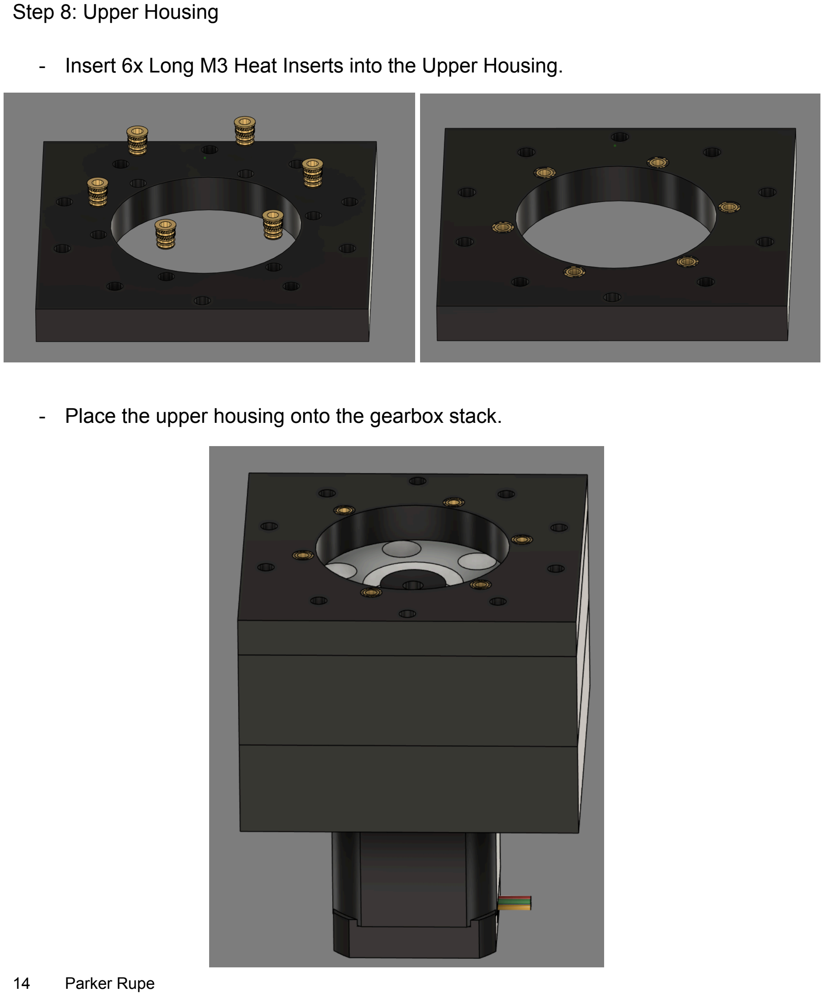
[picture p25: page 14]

Step 8: Upper Housing
- Insert 6x Long M3 Heat Inserts into the Upper Housing.
- Place the upper housing onto the gearbox stack.

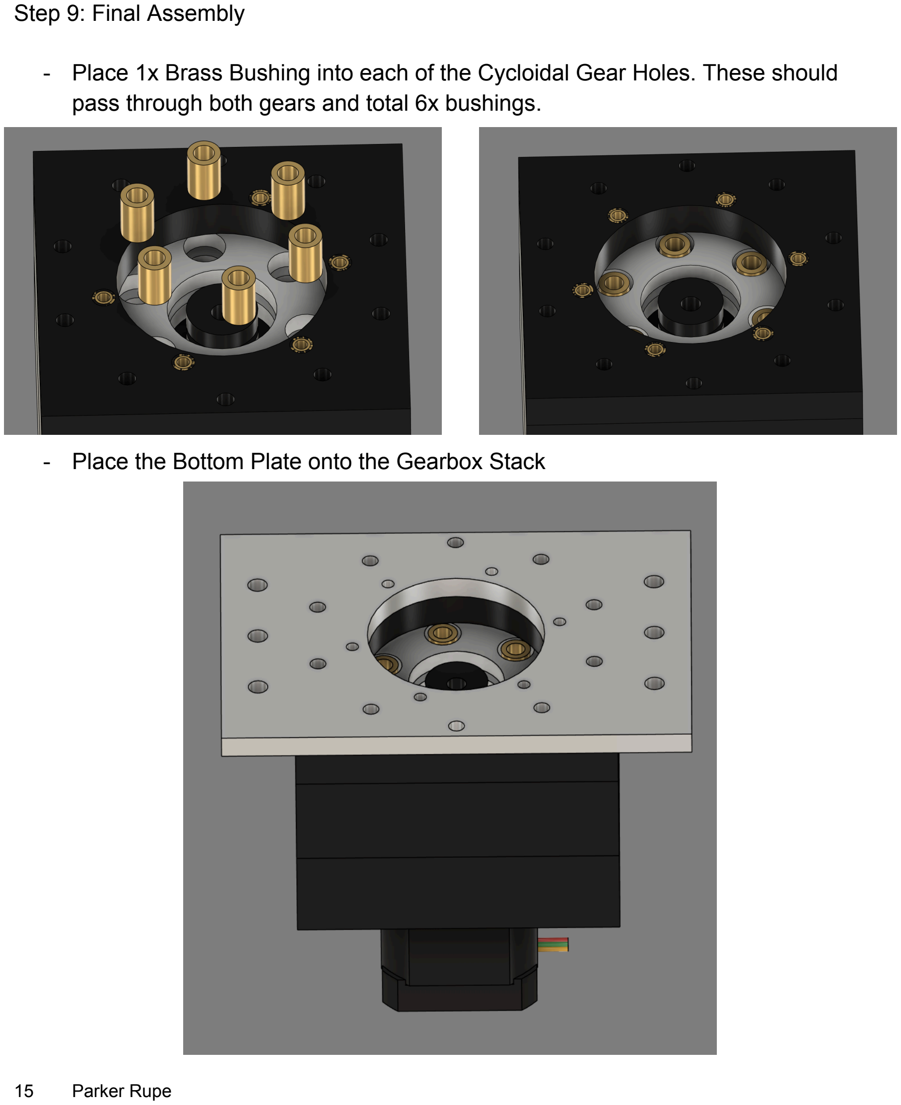
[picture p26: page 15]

Step 9: Final Assembly
- Place 1x Brass Bushing into each of the Cycloidal Gear Holes. These should pass through both gears and total 6x bushings.
- Place the Bottom Plate onto the Gearbox Stack

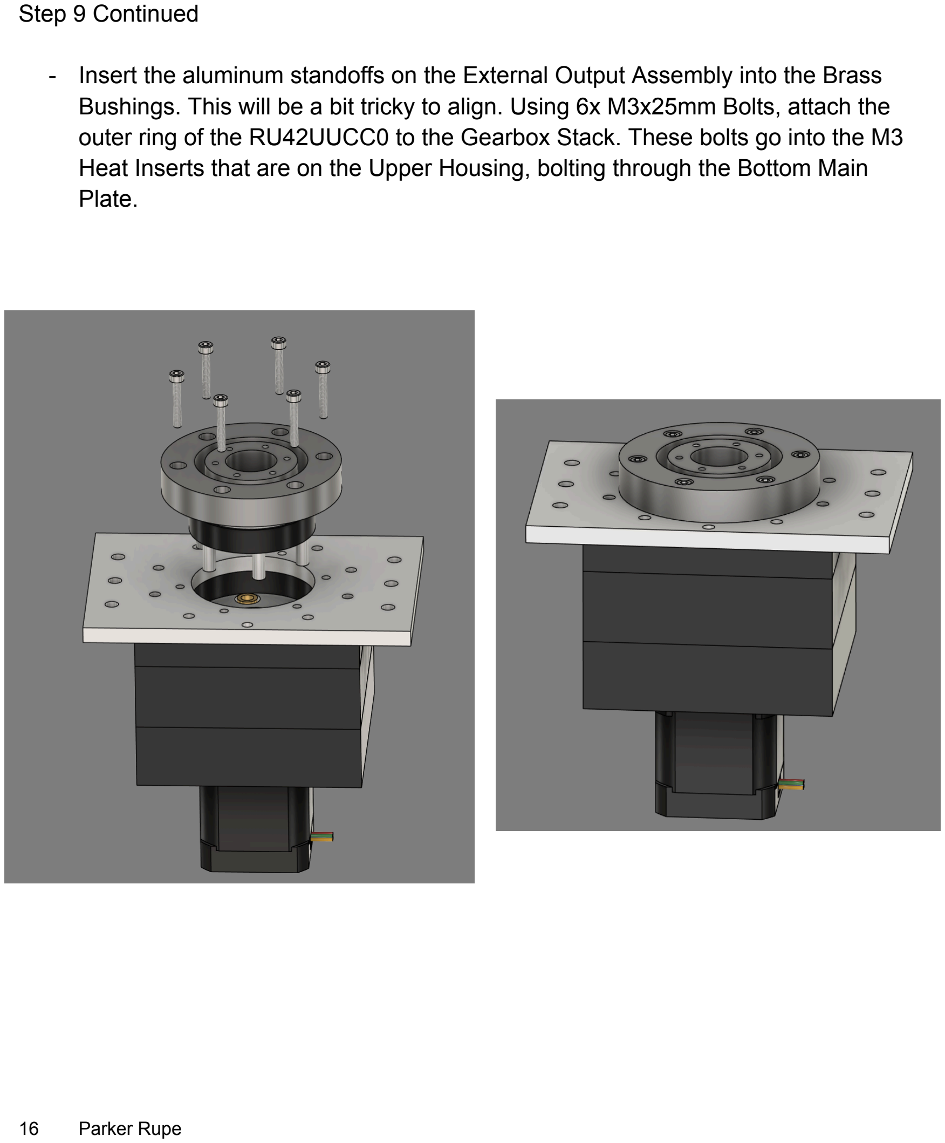
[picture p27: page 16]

Step 9 Continued
- Insert the aluminum standoffs on the External Output Assembly into the Brass Bushings. This will be a bit tricky to align. Using 6x M3x25mm Bolts, attach the outer ring of the RU42UUCC0 to the Gearbox Stack. These bolts go into the M3 Heat Inserts that are on the Upper Housing, bolting through the Bottom Main Plate.

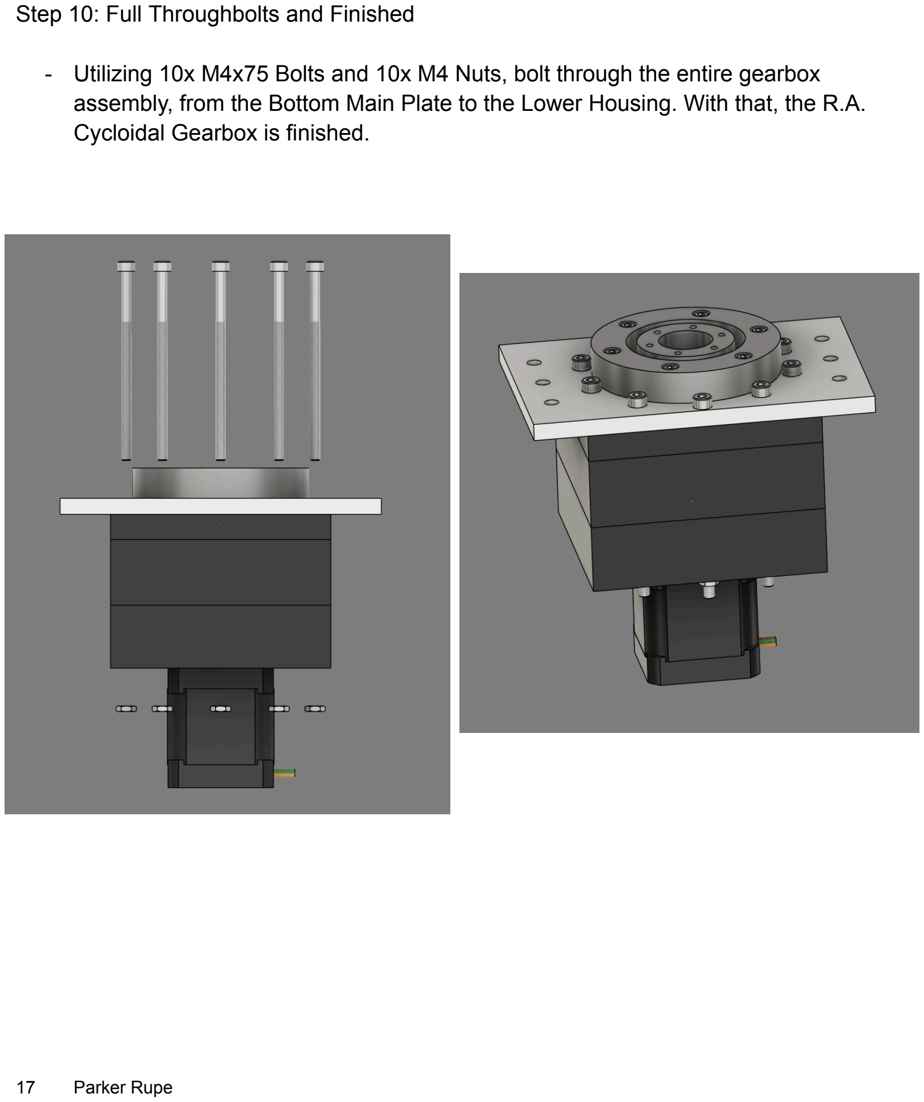
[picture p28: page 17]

Step 10: Full Throughbolts and Finished
- Utilizing 10x M4x75 Bolts and 10x M4 Nuts, bolt through the entire gearbox assembly, from the Bottom Main Plate to the Lower Housing. With that, the R.A. Cycloidal Gearbox is finished.

Step 11: Dec Gearbox
- Repeat steps 1-10 for the Dec gearbox, but substitute the Bottom Plate for the Front Plate. It should look like the following when complete:

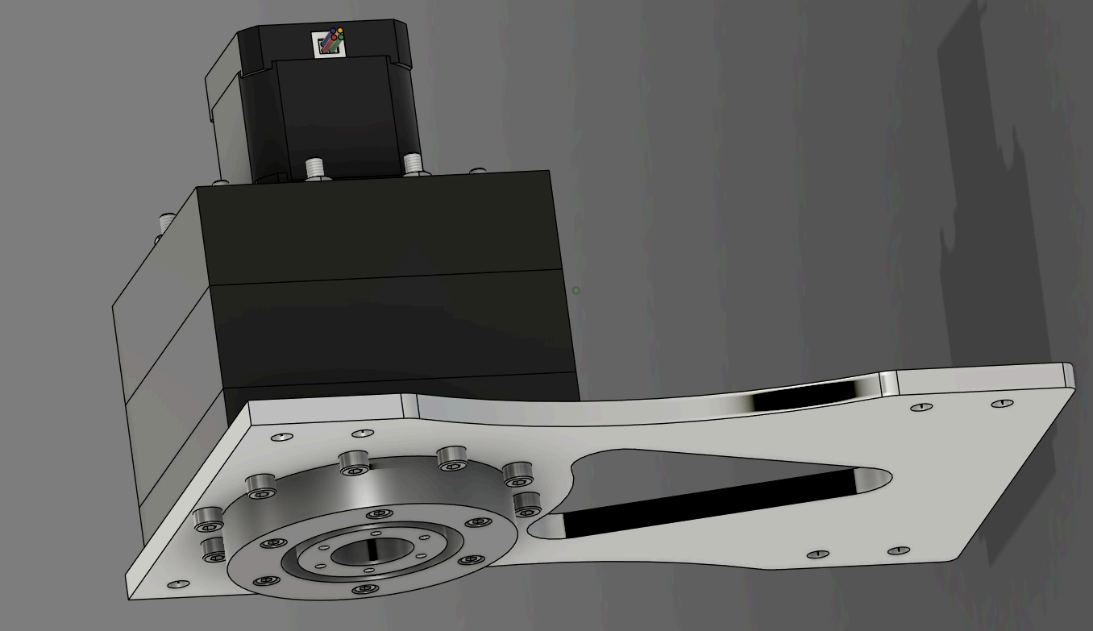
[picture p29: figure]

## Part 2: Frame and Final Assembly

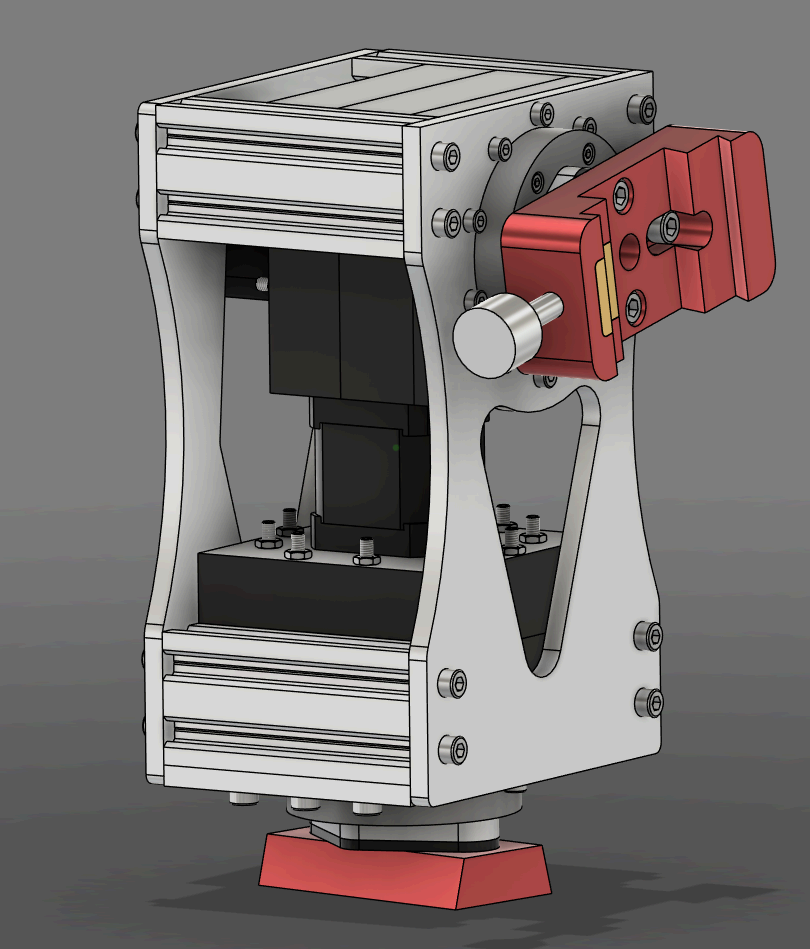
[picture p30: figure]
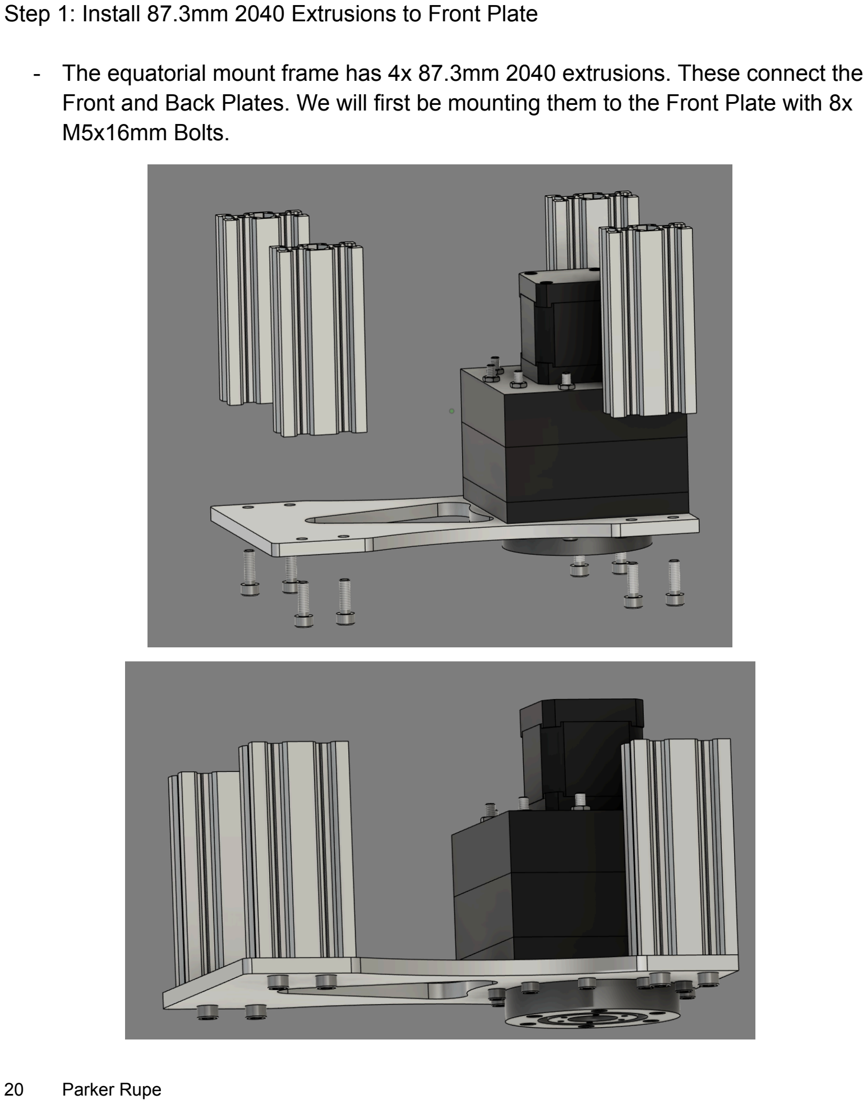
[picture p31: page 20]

Step 1: Install 87.3mm 2040 Extrusions to Front Plate
- The equatorial mount frame has 4x 87.3mm 2040 extrusions. These connect the Front and Back Plates. We will first be mounting them to the Front Plate with 8x M5x16mm Bolts.

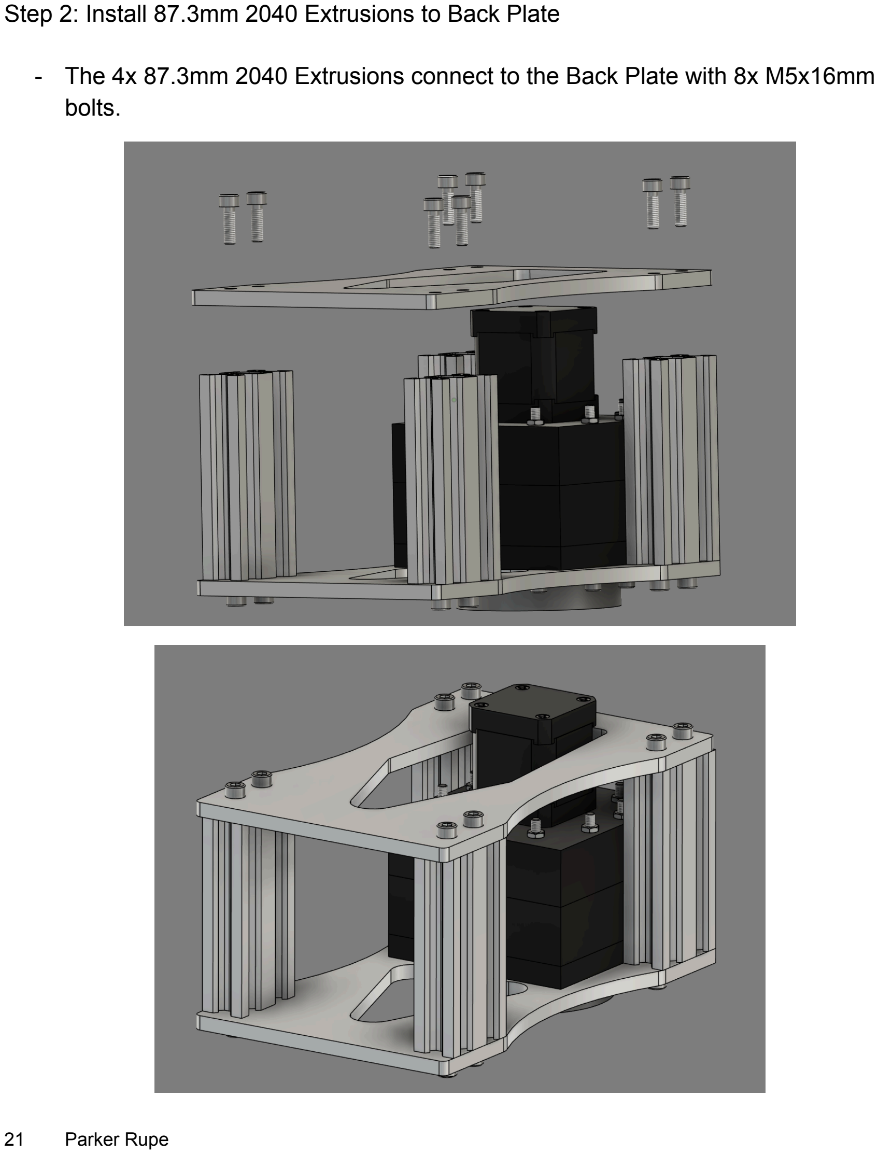
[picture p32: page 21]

Step 2: Install 87.3mm 2040 Extrusions to Back Plate
- The 4x 87.3mm 2040 Extrusions connect to the Back Plate with 8x M5x16mm bolts.

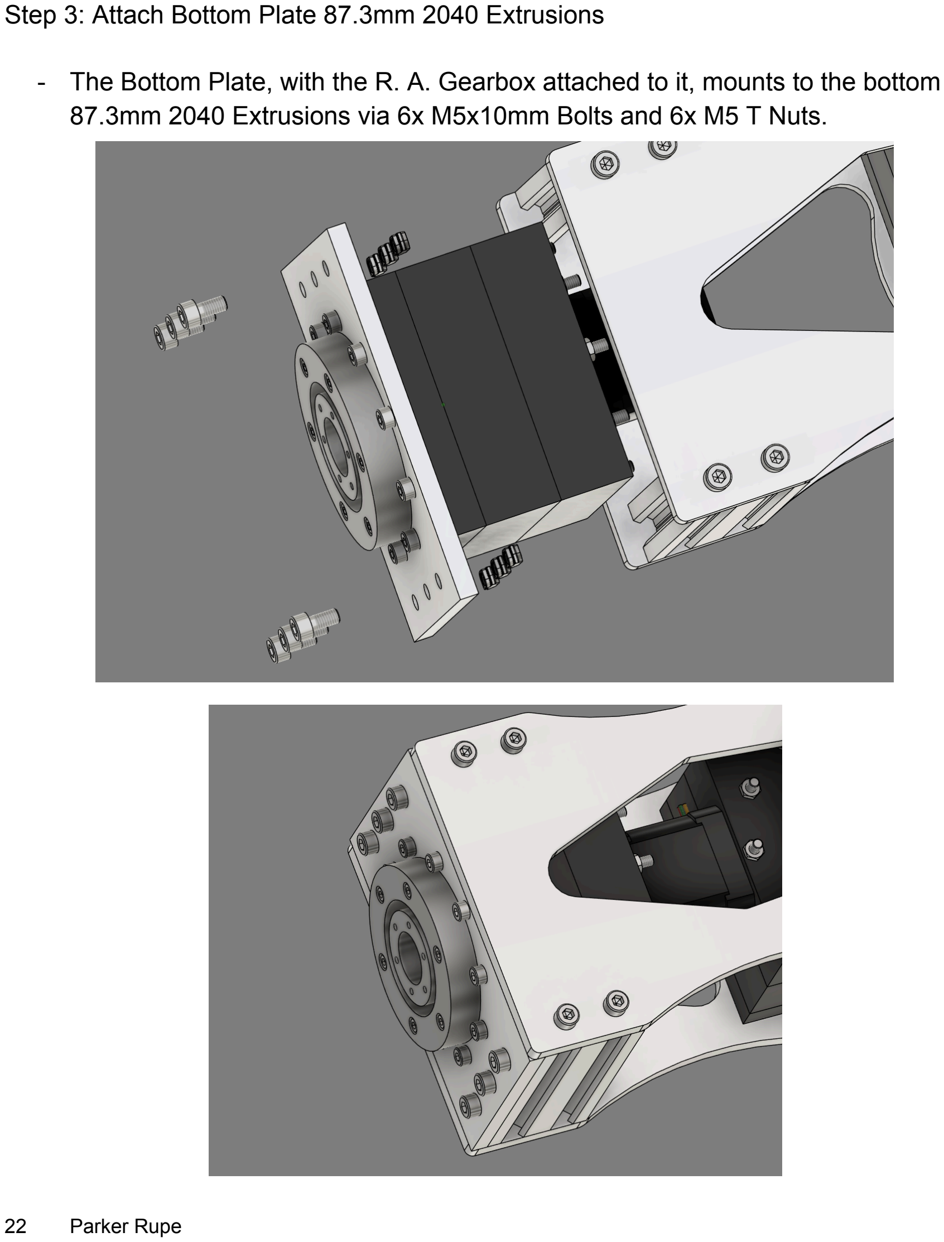
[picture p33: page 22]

Step 3: Attach Bottom Plate 87.3mm 2040 Extrusions
- The Bottom Plate, with the R. A. Gearbox attached to it, mounts to the bottom 87.3mm 2040 Extrusions via 6x M5x10mm Bolts and 6x M5 T Nuts.

Step 4: Attach Mount Vixen Rail with Adapter Plate
- For mounting the whole equatorial mount, the StarMount EQ has an 80mm Vixen Rail bolted to the base. This can be made longer, but I don’t believe it is needed. This requires an adapter plate and adapter spacer so that it can rigidly attach to the output of the R. A. Gearbox RU42UUCC0 bearing.

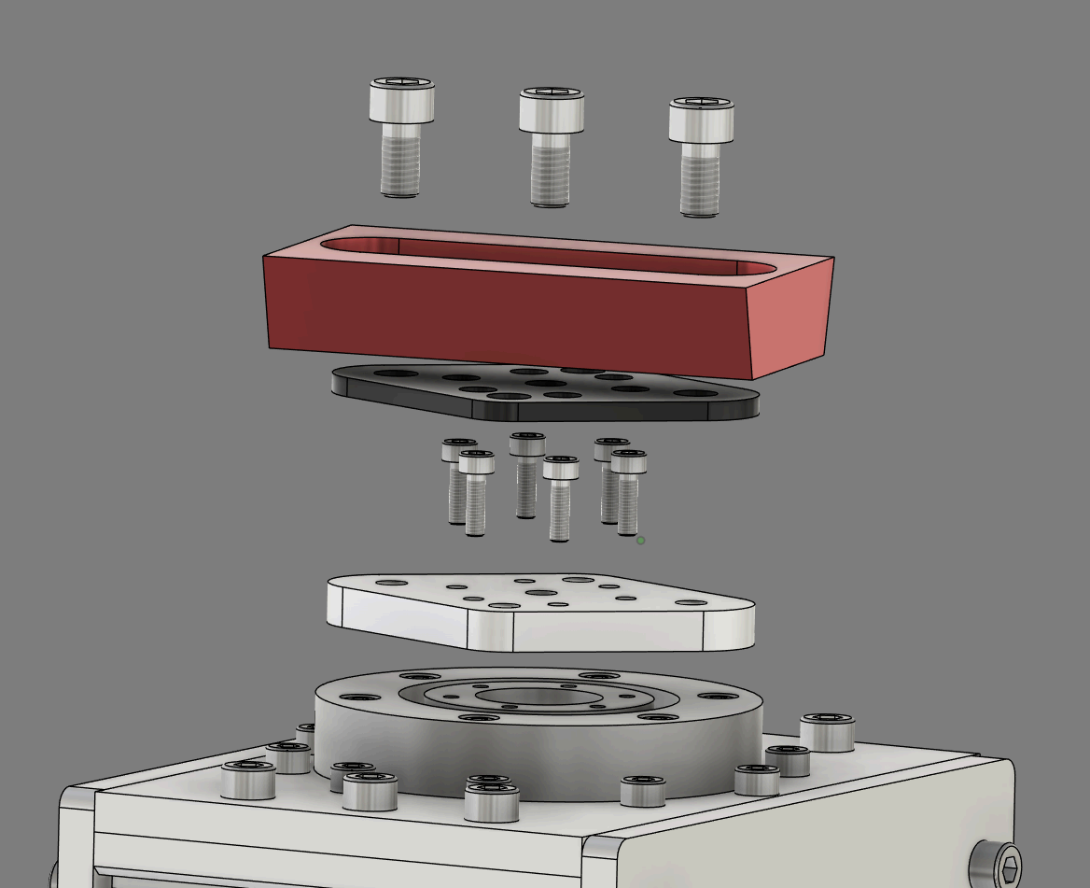
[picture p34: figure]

- The Adapter Plate is secured to the bearing output using 6x M3x10mm Bolts. The Vixen Rail then connects to the Adapter Plate through a printed Spacer via 3x M6x12mm Bolts.

Step 5: Attach Output Vixen Clamp and Adapter Plate
- For mounting equipment to the equatorial mount, the StarMount EQ has a Vixen Clamp bolted to the Dec Output.
This requires an adapter plate and adapter spacer so that it can rigidly attach to the output of the Dec Gearbox RU42UUCC0 bearing.

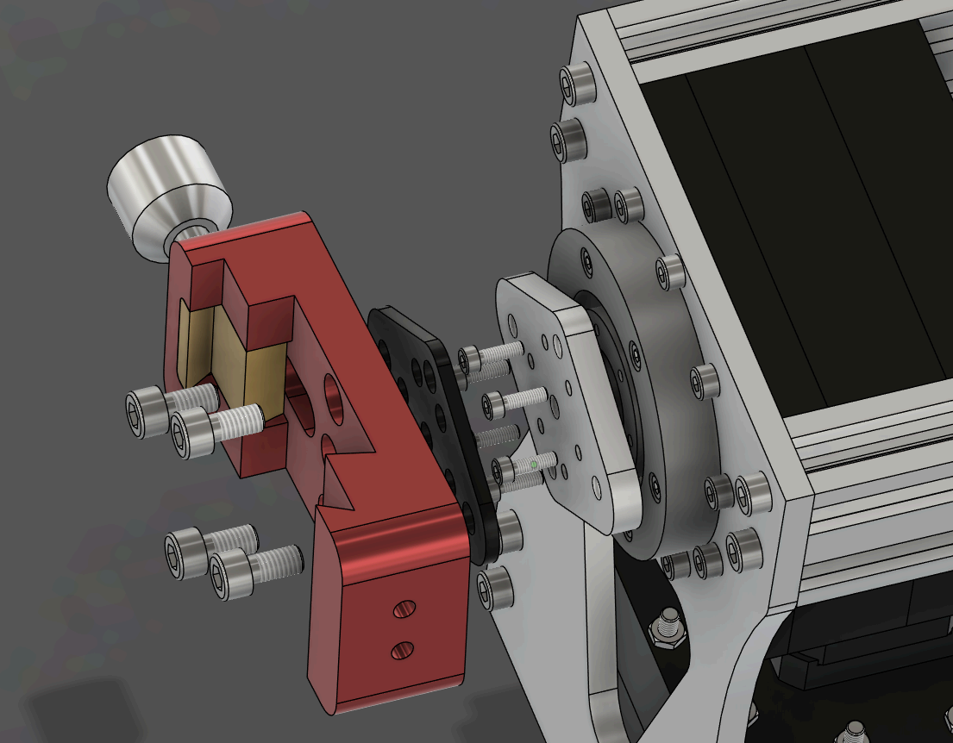
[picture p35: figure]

- The Adapter Plate is secured to the bearing output using 6x M3x10mm Bolts. The Vixen Clamp then connects to the Adapter Plate through a printed Spacer via 3x M6x12mm Bolts.

## With that, your SpaceMount Equatorial Mount is now Complete!

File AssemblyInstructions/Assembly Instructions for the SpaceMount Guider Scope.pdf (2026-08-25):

## Assembly Instructions for the SpaceMount Guider Scope

1 Parker Rupe

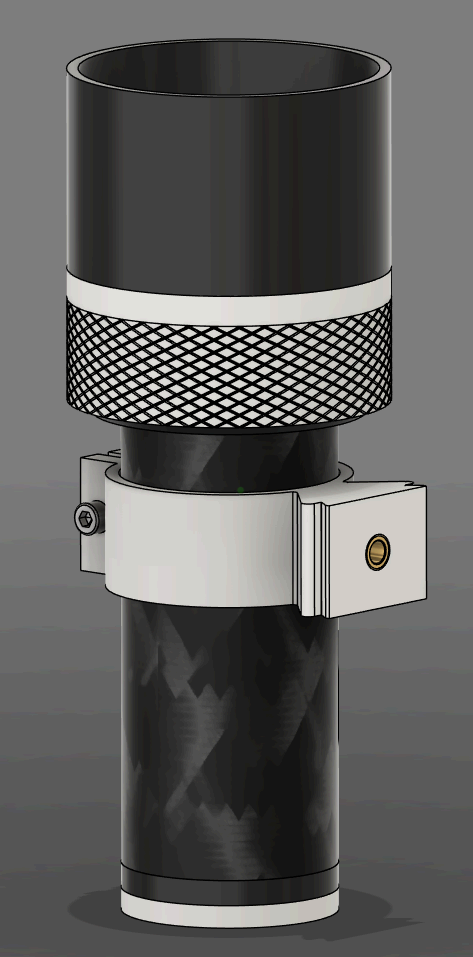
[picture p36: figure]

## Preface

This is the assembly guide for my Guider Scope that is part of my SpaceMount (https://github.com/ProgrammerTurtle/SpaceMount) project. It is certainly not error free, but it is written to the best of my abilities. Always refer to the master CAD assembly provided in the Github Repository for confirmation of assembly. Best of Luck!!

Note: Unless otherwise stated, assume screws are Socket Head Cap Screws (SHCS).

## Part 1: Camera Module

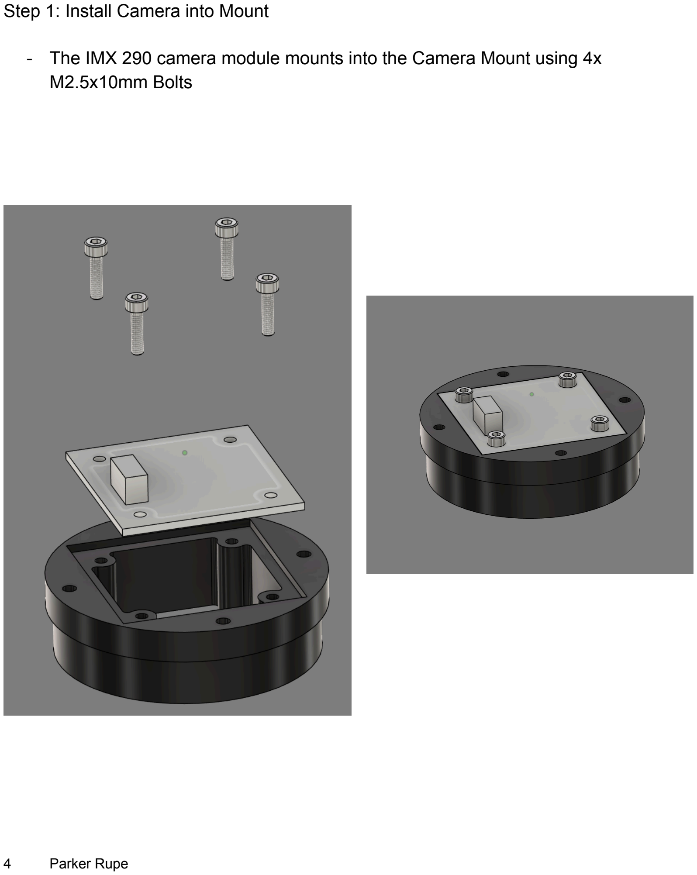
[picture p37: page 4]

Step 1: Install Camera into Mount
- The IMX 290 camera module mounts into the Camera Mount using 4x M2.5x10mm Bolts

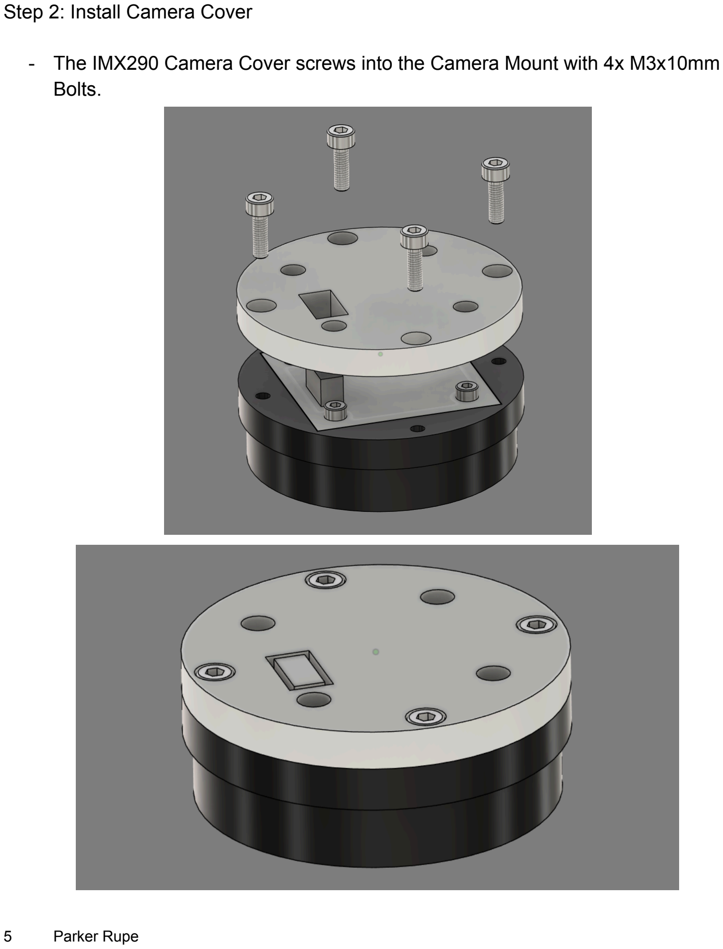
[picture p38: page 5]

Step 2: Install Camera Cover
- The IMX290 Camera Cover screws into the Camera Mount with 4x M3x10mm Bolts.

## Part 2: Focuser/Lens Holder

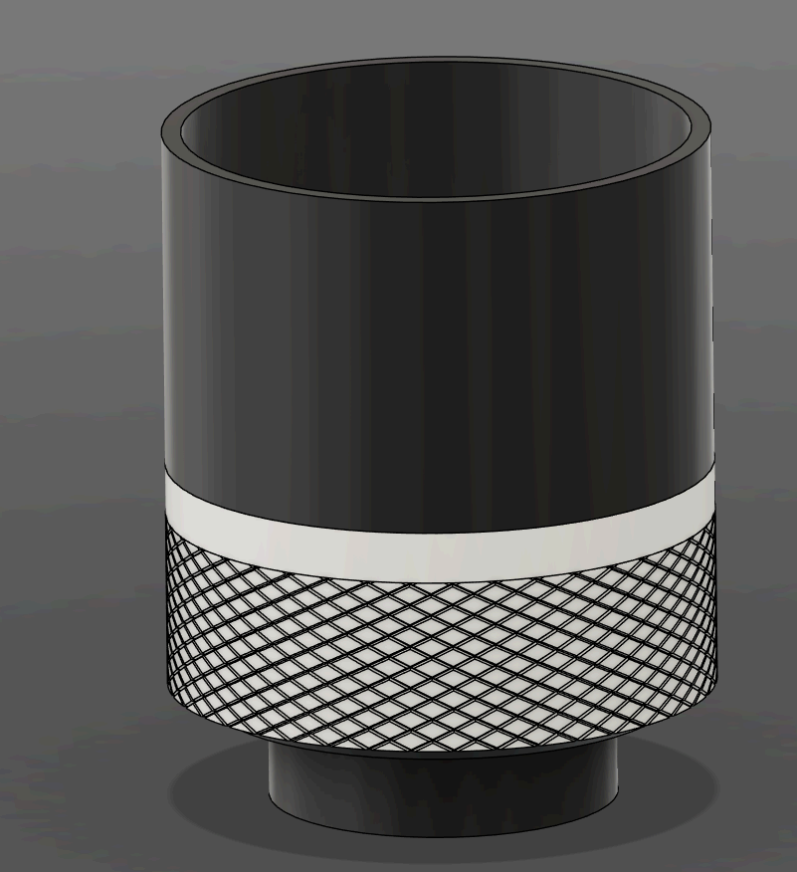
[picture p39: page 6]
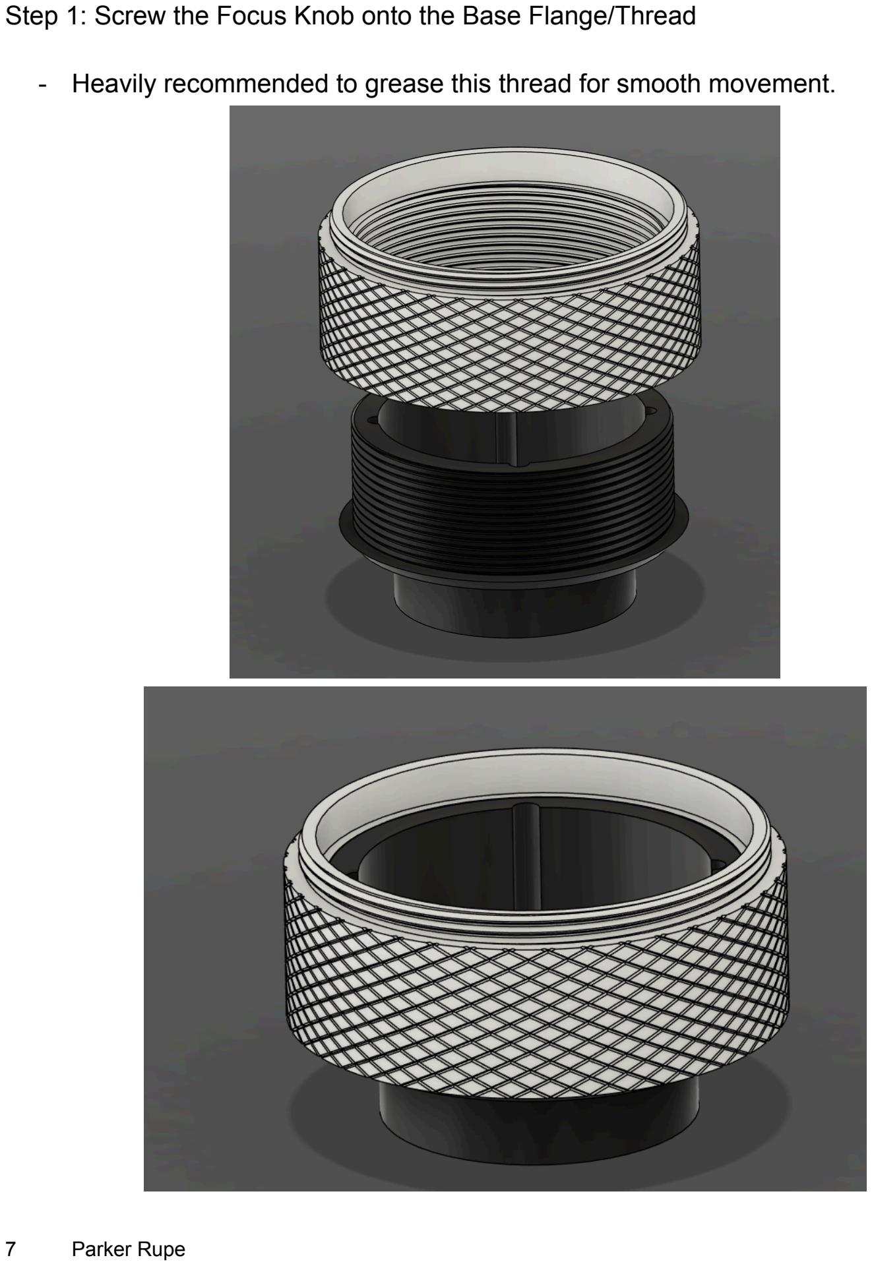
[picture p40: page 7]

Step 1: Screw the Focus Knob onto the Base Flange/Thread
- Heavily recommended to grease this thread for smooth movement.

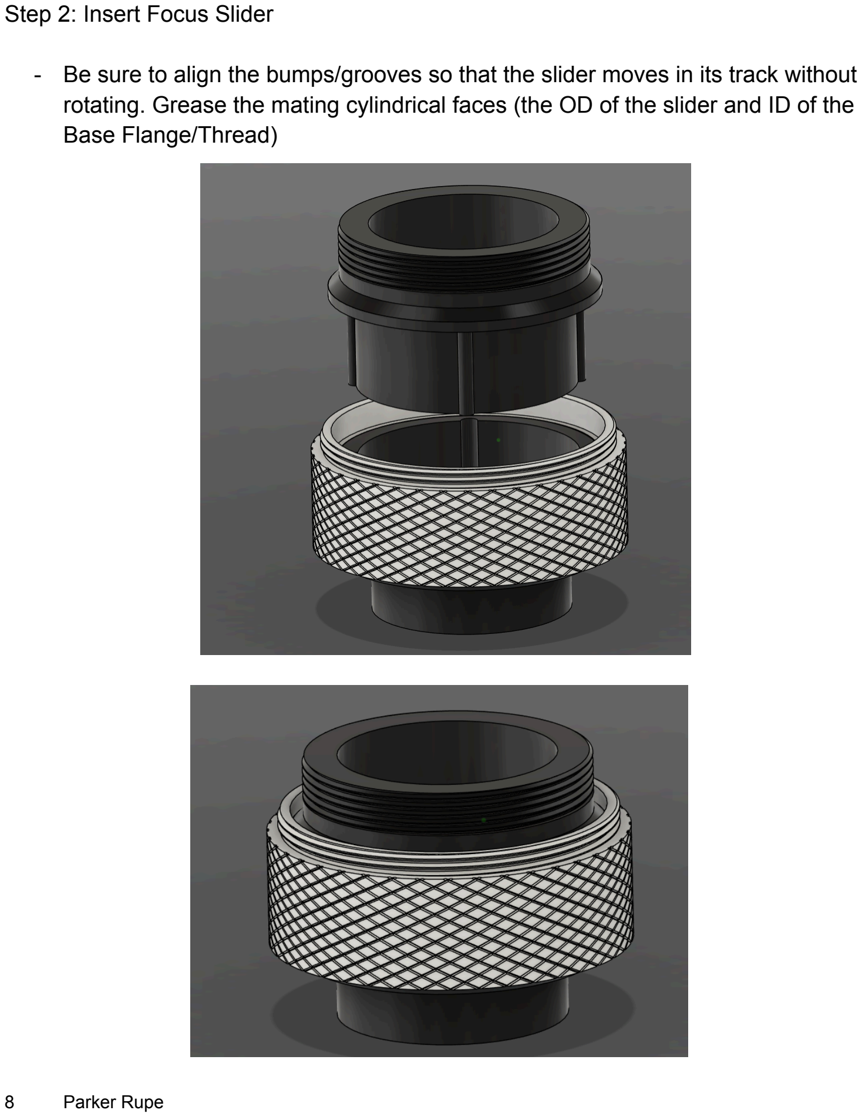
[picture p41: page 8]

Step 2: Insert Focus Slider
- Be sure to align the bumps/grooves so that the slider moves in its track without rotating. Grease the mating cylindrical faces (the OD of the slider and ID of the Base Flange/Thread)

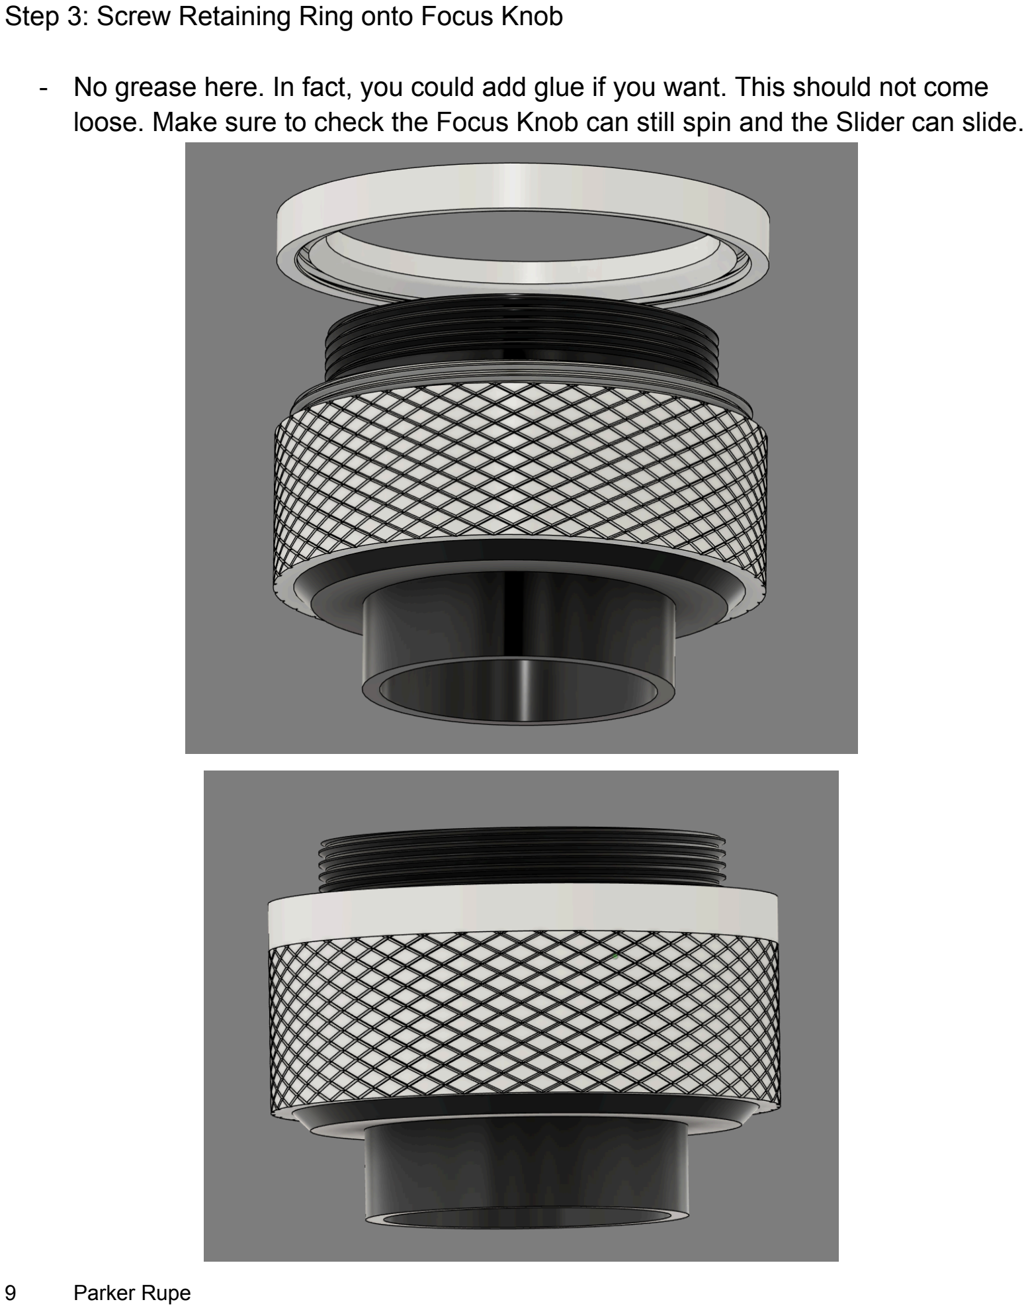
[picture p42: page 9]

Step 3: Screw Retaining Ring onto Focus Knob
- No grease here. In fact, you could add glue if you want. This should not come loose. Make sure to check the Focus Knob can still spin and the Slider can slide.

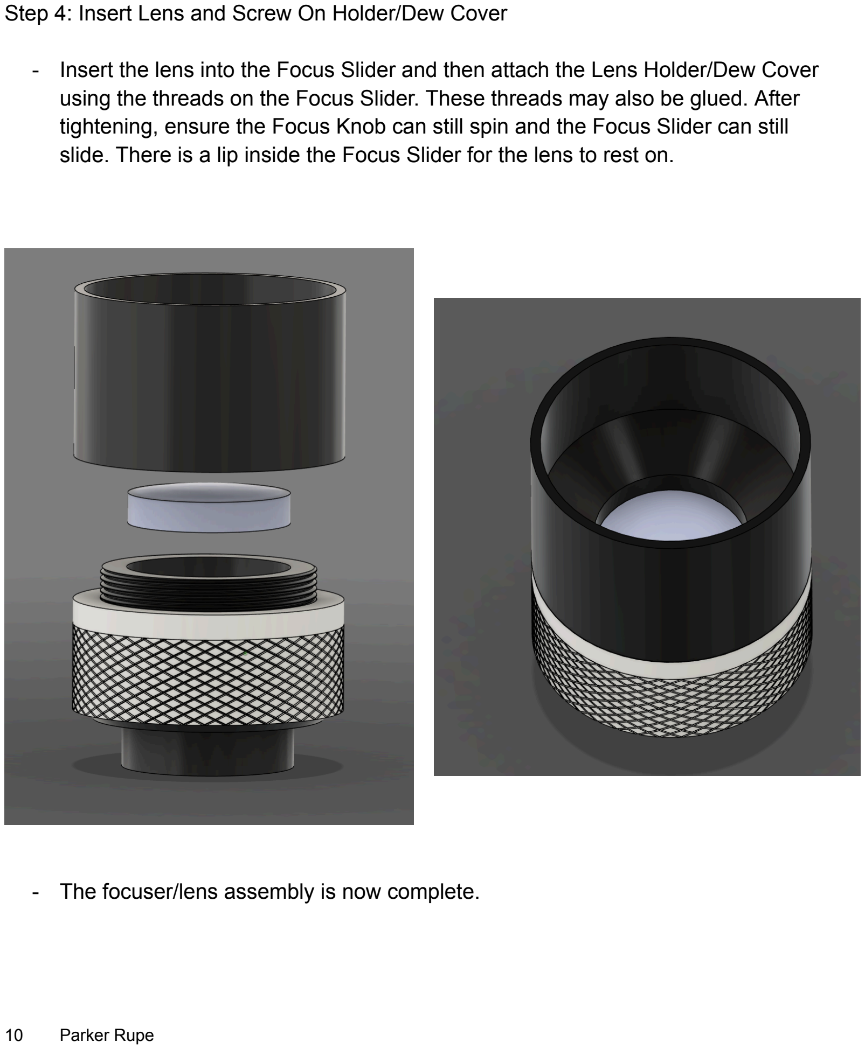
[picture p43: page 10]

Step 4: Insert Lens and Screw On Holder/Dew Cover
- Insert the lens into the Focus Slider and then attach the Lens Holder/Dew Cover using the threads on the Focus Slider. These threads may also be glued. After tightening, ensure the Focus Knob can still spin and the Focus Slider can still slide. There is a lip inside the Focus Slider for the lens to rest on.
- The focuser/lens assembly is now complete.

## Part 3: Bonding Parts Together

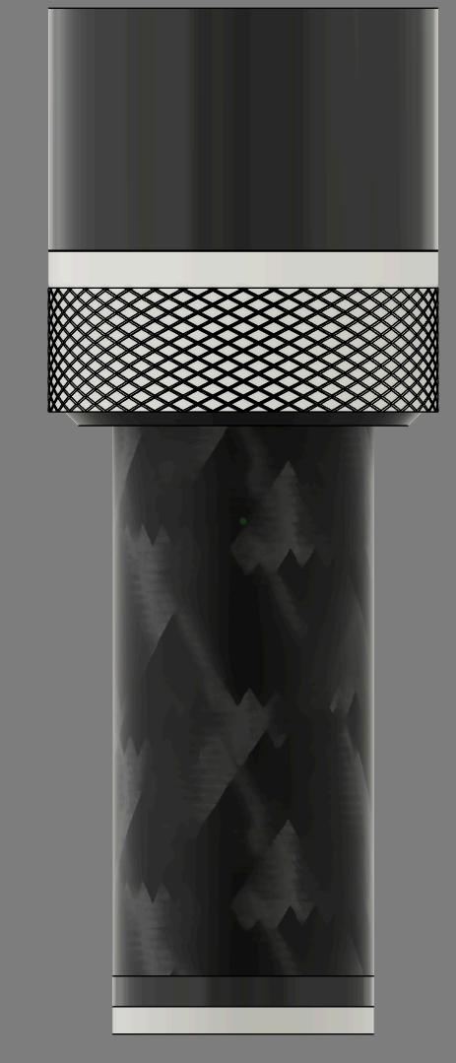
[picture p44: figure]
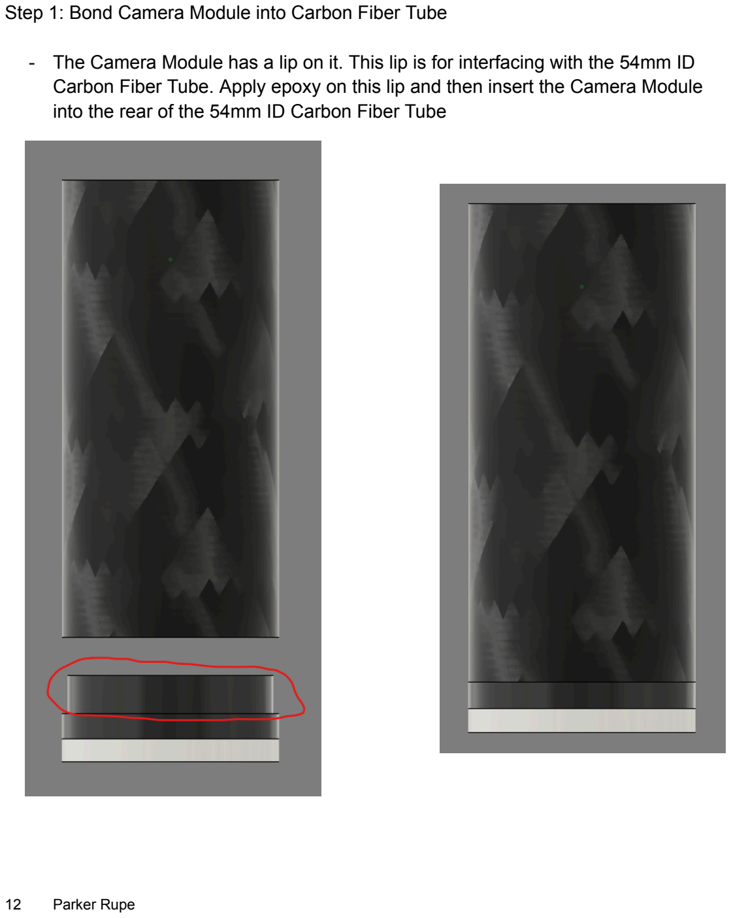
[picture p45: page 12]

Step 1: Bond Camera Module into Carbon Fiber Tube
- The Camera Module has a lip on it. This lip is for interfacing with the 54mm ID Carbon Fiber Tube. Apply epoxy on this lip and then insert the Camera Module into the rear of the 54mm ID Carbon Fiber Tube

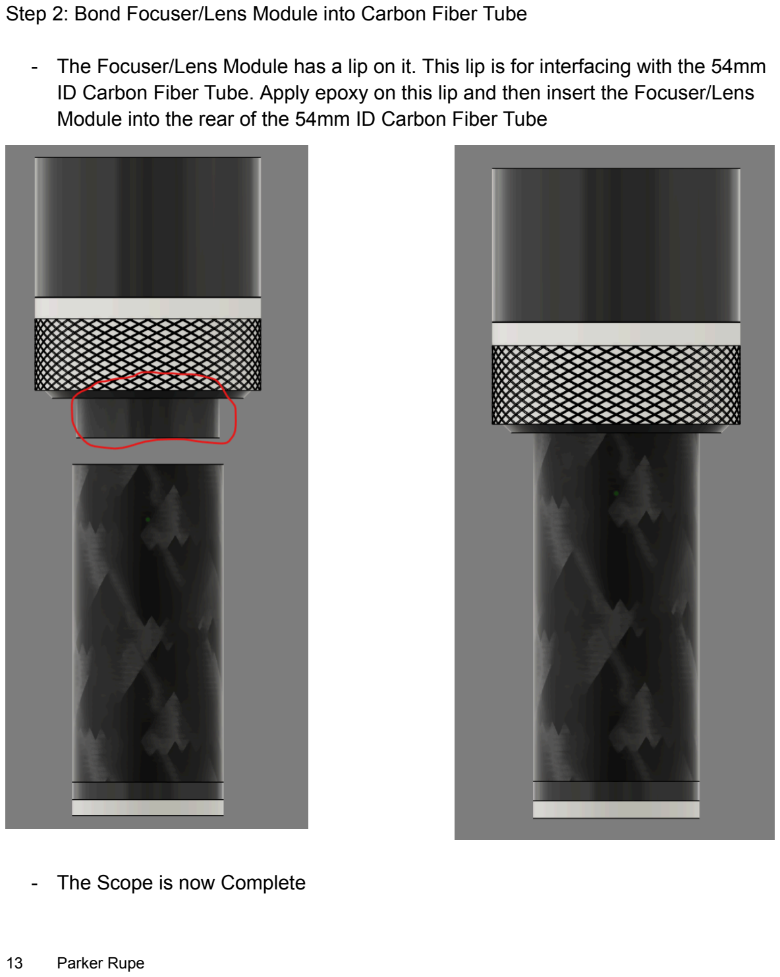
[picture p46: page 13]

Step 2: Bond Focuser/Lens Module into Carbon Fiber Tube
- The Focuser/Lens Module has a lip on it. This lip is for interfacing with the 54mm ID Carbon Fiber Tube. Apply epoxy on this lip and then insert the Focuser/Lens Module into the rear of the 54mm ID Carbon Fiber Tube
- The Scope is now Complete

## Part 3: Mounting

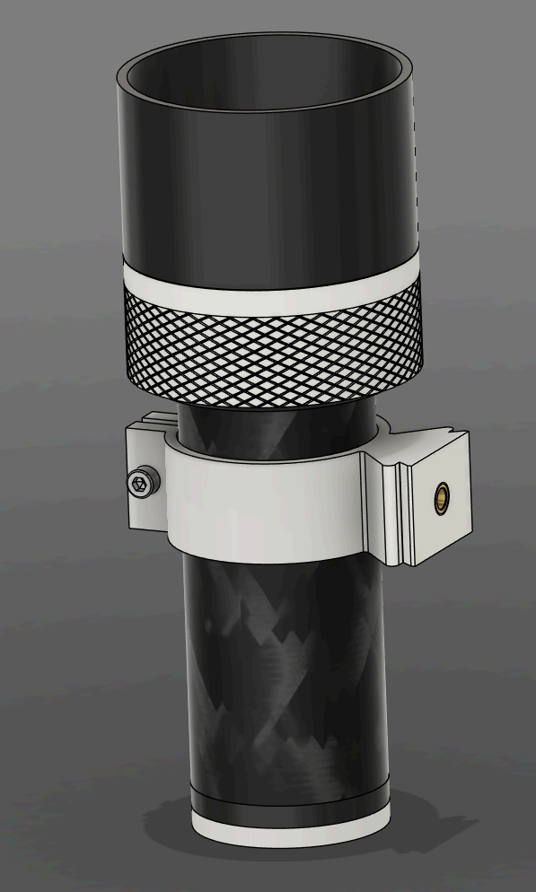
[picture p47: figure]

Step 1: Pick Option
- There are 2 mounting clamp options provided. One has a Mini Vixen rail on it, common on Guider scopes, while the other has an Arcaswiss rail. Both also sport M6 mounting holes via heat insert. For whichever option you choose, you must insert the M6 heat insert, an M5 nut, and an M5x20 Bolt.

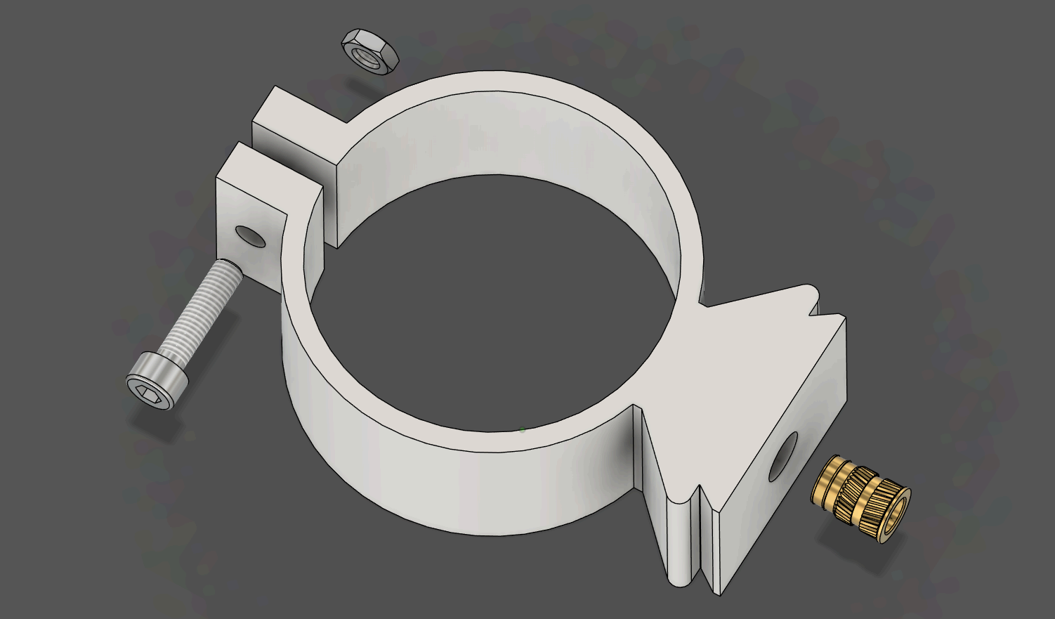
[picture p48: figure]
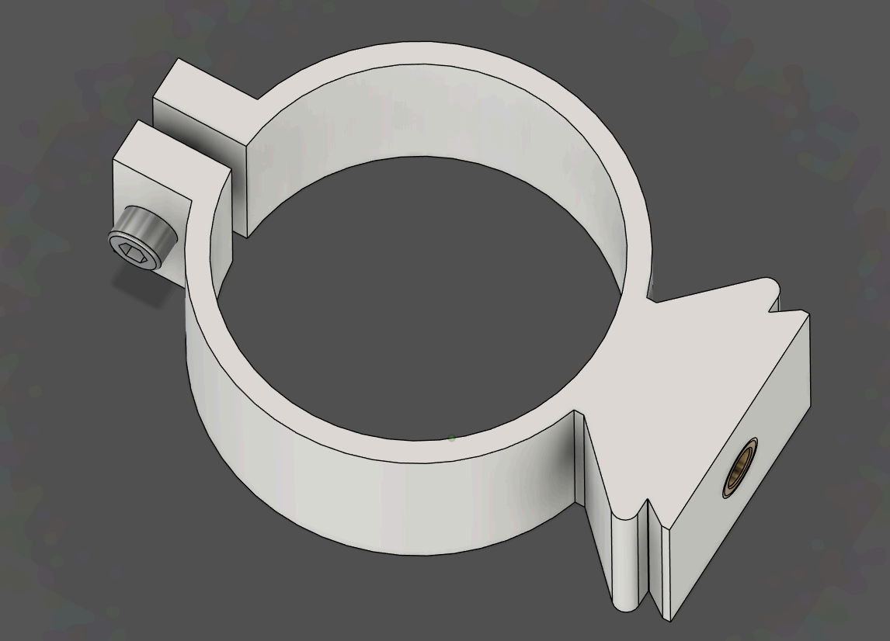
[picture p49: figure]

## With That, Your SpaceMount Guider Scope is Now Complete!

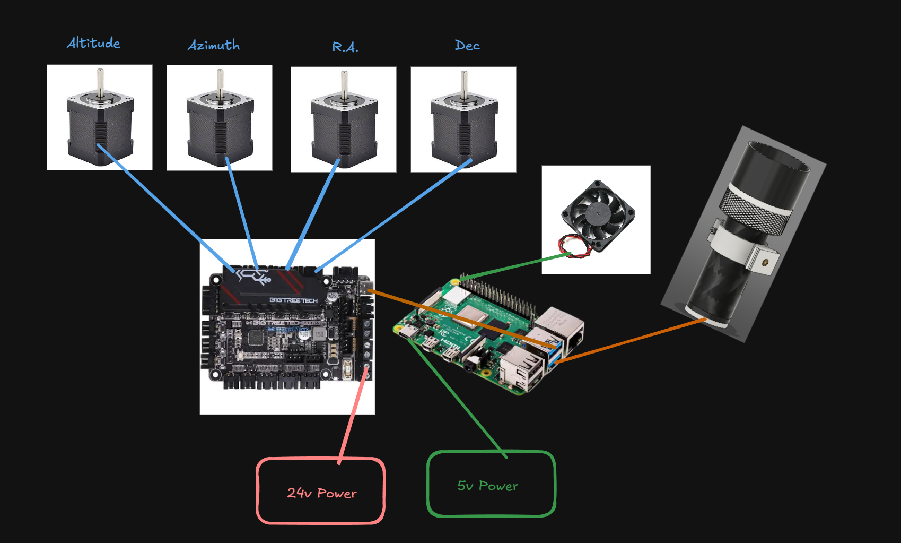
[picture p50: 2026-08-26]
AssemblyInstructions/SpaceMount Wiring Diagram.png

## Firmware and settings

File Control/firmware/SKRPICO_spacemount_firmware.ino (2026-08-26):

/*
 * SKR Pico Telescope Mount Firmware (RA/Dec/Az/Alt step generator)
 * ------------------------------------------------------------------
 * Target: BIGTREETECH SKR Pico V1.0 (RP2040), Arduino-Pico core
 *         (https://github.com/earlephilhower/arduino-pico)
 *
 * Role in the stack: this firmware does NOT know about sidereal rates,
 * coordinates, or GoTo targets. It only does two things:
 *   1. Generate precise step/dir pulses to the 4 onboard TMC2209s
 *   2. Accept simple serial commands from the Pi 4B telling it what
 *      rate to run at (continuous tracking) or how far to move (GoTo)
 *
 * All astronomy math (sidereal rate, RA/Dec targeting, INDI protocol
 * translation) lives in Python on the Pi 4B. This board is deliberately
 * "dumb" so it can be small and reliable.
 *
 * ------------------------------------------------------------------
 * PIN MAP - sourced from BIGTREETECH's own Klipper config
 * (github.com/bigtreetech/SKR-Pico and Klipper3d/klipper generic cfg)
 * ------------------------------------------------------------------
 *  Axis   Step   Dir    Enable   (active-low dir/enable per BTT cfg)
 *  X      GP11   GP10   GP12
 *  Y      GP6    GP5    GP7
 *  Z      GP19   GP28   GP2
 *  E0     GP14   GP13   GP15
 *
 *  Shared TMC2209 UART (single-wire, all 4 drivers on one bus):
 *  TX: GP8   RX: GP9
 *  UART addresses (per BTT's own default cfg - VERIFY against your
 *  board's MS1/MS2 jumper/address pins before trusting this, some
 *  SKR Pico revisions number them 0,2,1,3 rather than 0,1,2,3):
 *    X = 0, Y = 1(or 2), Z = 2(or 1), E0 = 3
 *
 * In this firmware, axis 0=X is mapped to RA, 1=Y to DEC,
 * 2=Z to AZ (polar align), 3=E0 to ALT (polar align).
 * Re-map AXIS_* below if you wire it differently.
 * ------------------------------------------------------------------
 *
 * SERIAL COMMAND PROTOCOL (USB CDC, 115200 baud, newline-terminated)
 * ------------------------------------------------------------------
 *   <AXIS>:RATE:<signed_steps_per_sec>      continuous run (tracking)
 *   <AXIS>:MOVE:<signed_steps>              relative move at MOVE_SPEED
 *   <AXIS>:STOP                             stop this axis now
 *   <AXIS>:EN:<0|1>                         driver enable/disable
 *   <AXIS>:MS:<1|2|4|8|16|32|64|128|256>    set microstepping
 *   PING                                    -> replies "OK"
 *
 *   <AXIS> is one of: RA DEC AZ ALT
 *
 *   Examples:
 *     RA:RATE:1350       (start continuous stepping for sidereal track)
 *     RA:STOP
 *     DEC:MOVE:-4000      (relative GoTo-style move)
 *     RA:MS:16
 *
 * Every command gets a single-line reply: "OK" or "ERR <reason>"
 * ------------------------------------------------------------------
 */

#include <Arduino.h>
#include <TMCStepper.h>          // https://github.com/teemuatlut/TMCStepper

// ---------------- User-tunable constants ----------------
#define SERIAL_BAUD        115200
#define R_SENSE            0.11f   // BTT TMC2209 default sense resistor
#define TMC_UART_ADDR_RA    0
#define TMC_UART_ADDR_DEC   1
#define TMC_UART_ADDR_AZ    2
#define TMC_UART_ADDR_ALT   3
#define DEFAULT_RUN_CURRENT_MA  600   // set to your motor's rated current
#define DEFAULT_MICROSTEPS      16
#define MOVE_SPEED_STEPS_PER_SEC 2000  // speed used for relative MOVE commands
#define MAX_RATE_STEPS_PER_SEC   8000  // safety clamp

// ---------------- Pin map (see header comment) ----------------
struct AxisPins {
  uint8_t step;
  uint8_t dir;
  uint8_t enable;
  uint8_t uartAddr;
  const char* name;
};

// index: 0=RA 1=DEC 2=AZ 3=ALT
AxisPins axisPins[4] = {
  { 11, 10, 12, TMC_UART_ADDR_RA,  "RA"  },  // X
  { 6,  5,  7,  TMC_UART_ADDR_DEC, "DEC" },  // Y
  { 19, 28, 2,  TMC_UART_ADDR_AZ,  "AZ"  },  // Z
  { 14, 13, 15, TMC_UART_ADDR_ALT, "ALT" },  // E0
};

#define UART_TX_PIN 8
#define UART_RX_PIN 9

// ---------------- Per-axis runtime state ----------------
struct AxisState {
  volatile bool running = false;
  volatile bool dir = true;          // true = positive direction
  volatile uint32_t intervalUs = 0;  // microseconds between step pulses
  volatile int32_t stepsRemaining = 0; // for MOVE commands; <0 = infinite (RATE)
  repeating_timer_t timer;
  bool timerActive = false;
};

AxisState axisState[4];

// One shared UART for all 4 TMC2209s (single-wire PDN_UART bus)
// Use a hardware UART on the Pico; SoftwareSerial also works if needed.
HardwareSerial &tmcSerial = Serial2; // wire GP8/GP9 to Serial2 in variant, see note below

TMC2209Stepper driver[4] = {
  TMC2209Stepper(&tmcSerial, R_SENSE, TMC_UART_ADDR_RA),
  TMC2209Stepper(&tmcSerial, R_SENSE, TMC_UART_ADDR_DEC),
  TMC2209Stepper(&tmcSerial, R_SENSE, TMC_UART_ADDR_AZ),
  TMC2209Stepper(&tmcSerial, R_SENSE, TMC_UART_ADDR_ALT),
};

// ---------------- Step ISR (one repeating timer per axis) ----------------
// Runs in interrupt context: keep it minimal - just toggle STEP pin and
// decrement step count. All the "what rate should this axis run at" logic
// happens outside the ISR, in the command handler.
bool stepISR(struct repeating_timer *rt) {
  int axisIdx = (int)(intptr_t)rt->user_data;
  AxisState &st = axisState[axisIdx];
  AxisPins &pins = axisPins[axisIdx];

  if (!st.running) return true; // keep timer alive but idle, cheap check

  // pulse STEP high then low (TMC2209 needs only a short high pulse,
  // ~a few hundred ns minimum - a couple of NOPs/digitalWrite round trip
  // is plenty at these step rates)
  digitalWrite(pins.step, HIGH);
  delayMicroseconds(2);
  digitalWrite(pins.step, LOW);

  if (st.stepsRemaining > 0) {
    st.stepsRemaining--;
    if (st.stepsRemaining == 0) {
      st.running = false;
    }
  }
  // stepsRemaining < 0 means "run forever" (RATE mode / tracking) - never decremented

  return true; // true = keep repeating
}

// ---------------- Axis control helpers ----------------
void setAxisDirection(int idx, bool positive) {
  AxisPins &pins = axisPins[idx];
  axisState[idx].dir = positive;
  digitalWrite(pins.dir, positive ? HIGH : LOW);
}

void stopAxis(int idx) {
  axisState[idx].running = false;
  if (axisState[idx].timerActive) {
    cancel_repeating_timer(&axisState[idx].timer);
    axisState[idx].timerActive = false;
  }
}

// Start (or retarget) an axis at a given signed step rate.
// stepCount < 0 means "run forever" (continuous tracking / RATE command).
// stepCount >= 0 means "run exactly this many steps then stop" (MOVE command).
void startAxis(int idx, float stepsPerSec, int32_t stepCount) {
  AxisState &st = axisState[idx];

  // stop any existing timer on this axis before reconfiguring
  stopAxis(idx);

  bool positive = stepsPerSec >= 0;
  float absRate = fabs(stepsPerSec);
  if (absRate < 0.01f) return; // essentially zero, nothing to do
  if (absRate > MAX_RATE_STEPS_PER_SEC) absRate = MAX_RATE_STEPS_PER_SEC;

  setAxisDirection(idx, positive);

  st.stepsRemaining = stepCount; // -1 => infinite, run() decrements only if >0
  st.intervalUs = (uint32_t)(1000000.0f / absRate);
  st.running = true;

  // negative delay = "delay from start of previous callback" -> stable rate
  add_repeating_timer_us(-(int32_t)st.intervalUs, stepISR, (void*)(intptr_t)idx, &st.timer);
  st.timerActive = true;
}

int axisIndexFromName(const String &name) {
  for (int i = 0; i < 4; i++) {
    if (name.equalsIgnoreCase(axisPins[i].name)) return i;
  }
  return -1;
}

void setMicrosteps(int idx, uint16_t ms) {
  driver[idx].microsteps(ms);
}

void setEnable(int idx, bool en) {
  // BTT SKR Pico enable pins are active-low per Klipper cfg (!gpioX)
  digitalWrite(axisPins[idx].enable, en ? LOW : HIGH);
}

// ---------------- Serial command parsing ----------------
String inputLine;

void handleCommand(String line) {
  line.trim();
  if (line.length() == 0) return;

  if (line.equalsIgnoreCase("PING")) {
    Serial.println("OK");
    return;
  }

  int firstColon = line.indexOf(':');
  if (firstColon < 0) {
    Serial.println("ERR malformed");
    return;
  }

  String axisName = line.substring(0, firstColon);
  String rest = line.substring(firstColon + 1);
  int idx = axisIndexFromName(axisName);
  if (idx < 0) {
    Serial.println("ERR unknown_axis");
    return;
  }

  int secondColon = rest.indexOf(':');
  String action = (secondColon >= 0) ? rest.substring(0, secondColon) : rest;
  String param   = (secondColon >= 0) ? rest.substring(secondColon + 1) : "";

  if (action.equalsIgnoreCase("RATE")) {
    float rate = param.toFloat();
    startAxis(idx, rate, -1); // -1 = run forever, this is tracking mode
    Serial.println("OK");

  } else if (action.equalsIgnoreCase("MOVE")) {
    long steps = param.toInt();
    if (steps == 0) { Serial.println("OK"); return; }
    float rate = (steps > 0) ? MOVE_SPEED_STEPS_PER_SEC : -MOVE_SPEED_STEPS_PER_SEC;
    startAxis(idx, rate, labs(steps));
    Serial.println("OK");

  } else if (action.equalsIgnoreCase("STOP")) {
    stopAxis(idx);
    Serial.println("OK");

  } else if (action.equalsIgnoreCase("EN")) {
    setEnable(idx, param.toInt() != 0);
    Serial.println("OK");

  } else if (action.equalsIgnoreCase("MS")) {
    int ms = param.toInt();
    setMicrosteps(idx, (uint16_t)ms);
    Serial.println("OK");

  } else {
    Serial.println("ERR unknown_action");
  }
}

// ---------------- Setup / loop ----------------
void setup() {
  Serial.begin(SERIAL_BAUD);
  // Arduino-Pico (earlephilhower core) remaps UART pins like this,
  // BEFORE calling begin() - NOT the ESP32-style 4-argument begin().
  tmcSerial.setRX(UART_RX_PIN);
  tmcSerial.setTX(UART_TX_PIN);
  tmcSerial.begin(115200);

  for (int i = 0; i < 4; i++) {
    pinMode(axisPins[i].step, OUTPUT);
    pinMode(axisPins[i].dir, OUTPUT);
    pinMode(axisPins[i].enable, OUTPUT);
    digitalWrite(axisPins[i].step, LOW);
    setEnable(i, false); // start disabled until Pi explicitly enables

    driver[i].begin();
    driver[i].toff(4);
    driver[i].rms_current(DEFAULT_RUN_CURRENT_MA);
    driver[i].microsteps(DEFAULT_MICROSTEPS);
    driver[i].pwm_autoscale(true);
    driver[i].en_spreadCycle(false); // stealthChop by default; disable for
                                      // higher-torque spreadCycle if tracking
                                      // smoothness matters more than noise
  }

  Serial.println("READY mount_firmware skr_pico v0.1");
}

void loop() {
  while (Serial.available()) {
    char c = Serial.read();
    if (c == '\n' || c == '\r') {
      if (inputLine.length() > 0) {
        handleCommand(inputLine);
        inputLine = "";
      }
    } else {
      inputLine += c;
    }
  }
}

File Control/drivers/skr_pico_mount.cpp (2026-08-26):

#include "skr_pico_mount.h"

#include <cstring>
#include <cmath>
#include <memory>
#include <termios.h>

#include <indicom.h>   // tty_read, tty_write_string, etc.

static std::unique_ptr<SKRPicoMount> mount(new SKRPicoMount());

SKRPicoMount::SKRPicoMount()
{
    // TELESCOPE_HAS_PULSE_GUIDING: required for PHD2's INDI mount guiding
    // TELESCOPE_CAN_ABORT / CAN_SYNC / CAN_GOTO: basic mount capabilities
    // TELESCOPE_HAS_TRACK_MODE / TRACK_RATE: sidereal + custom rate support
    SetTelescopeCapability(
        TELESCOPE_CAN_GOTO |
        TELESCOPE_CAN_SYNC |
        TELESCOPE_CAN_ABORT |
        TELESCOPE_HAS_TRACK_MODE |
        TELESCOPE_HAS_TRACK_RATE |
        TELESCOPE_HAS_PULSE_GUIDING,
        4 /* slew rate count, unused meaningfully here but required */
    );

    setTelescopeConnection(CONNECTION_SERIAL);
}

const char *SKRPicoMount::getDefaultName()
{
    return "SKR Pico Cycloidal Mount";
}

bool SKRPicoMount::initProperties()
{
    INDI::Telescope::initProperties();
    INDI::GuiderInterface::initGuiderProperties(getDeviceName(), MOTION_TAB);

    addAuxControls();

    // Reasonable default baud for the serial connection plugin
    serialConnection->setDefaultBaudRate(Connection::Serial::B_115200);

    return true;
}

bool SKRPicoMount::updateProperties()
{
    INDI::Telescope::updateProperties();

    if (isConnected())
    {
        defineProperty(GuideNSNP);
        defineProperty(GuideWENP);
    }
    else
    {
        deleteProperty(GuideNSNP.name);
        deleteProperty(GuideWENP.name);
    }

    return true;
}

// ---------------------------------------------------------------------
// Connection handshake - confirm the SKR Pico firmware is alive and
// responding, using the PING command from its serial protocol.
// ---------------------------------------------------------------------
bool SKRPicoMount::Handshake()
{
    PortFD = serialConnection->getPortFD();

    char response[32] = {0};
    if (!sendCommand("PING\n", response, sizeof(response)))
    {
        LOG_ERROR("No response from SKR Pico firmware (PING failed).");
        return false;
    }

    if (strncmp(response, "OK", 2) != 0)
    {
        LOGF_ERROR("Unexpected handshake response: %s", response);
        return false;
    }

    LOG_INFO("SKR Pico mount firmware responded to PING - connected.");

    // Enable both drivers and set microstepping to match our constants
    sendAxisCommand("RA", "EN", 1);
    sendAxisCommand("DEC", "EN", 1);
    sendAxisCommand("RA", "MS", MICROSTEPS);
    sendAxisCommand("DEC", "MS", MICROSTEPS);

    return true;
}

// ---------------------------------------------------------------------
// Low-level serial helpers
// ---------------------------------------------------------------------
bool SKRPicoMount::sendCommand(const char *cmd, char *response, size_t responseLen)
{
    int nbytes_written = 0, nbytes_read = 0, rc = 0;

    tcflush(PortFD, TCIOFLUSH);

    rc = tty_write_string(PortFD, cmd, &nbytes_written);
    if (rc != TTY_OK)
    {
        char errmsg[MAXRBUF];
        tty_error_msg(rc, errmsg, MAXRBUF);
        LOGF_ERROR("Serial write error: %s", errmsg);
        return false;
    }

    rc = tty_nread_section(PortFD, response, responseLen - 1, '\n', 2 /*timeout sec*/, &nbytes_read);
    if (rc != TTY_OK)
    {
        char errmsg[MAXRBUF];
        tty_error_msg(rc, errmsg, MAXRBUF);
        LOGF_ERROR("Serial read error: %s", errmsg);
        return false;
    }
    response[nbytes_read] = '\0';

    return true;
}

bool SKRPicoMount::sendAxisCommand(const char *axis, const char *action, double param)
{
    char cmd[64];
    // integer-friendly formatting for step counts/rates; RATE also
    // accepts fractional steps/sec if you want finer than integer rates
    snprintf(cmd, sizeof(cmd), "%s:%s:%.3f\n", axis, action, param);

    char response[32] = {0};
    if (!sendCommand(cmd, response, sizeof(response)))
        return false;

    if (strncmp(response, "OK", 2) != 0)
    {
        LOGF_WARN("Axis command '%s' got non-OK response: %s", cmd, response);
        return false;
    }
    return true;
}

bool SKRPicoMount::sendAxisCommandStr(const char *axis, const char *action, const char *param)
{
    char cmd[64];
    snprintf(cmd, sizeof(cmd), "%s:%s:%s\n", axis, action, param);

    char response[32] = {0};
    if (!sendCommand(cmd, response, sizeof(response)))
        return false;

    return strncmp(response, "OK", 2) == 0;
}

// ---------------------------------------------------------------------
// Coordinate / rate math
// ---------------------------------------------------------------------
double SKRPicoMount::arcsecPerSecToStepsPerSec(double arcsecPerSec, double gearRatio, int stepsPerRev, int microsteps)
{
    // 1 full output-shaft revolution = 360*3600 arcsec
    double stepsPerOutputRev = stepsPerRev * microsteps * gearRatio;
    double arcsecPerStep = (360.0 * 3600.0) / stepsPerOutputRev;
    return arcsecPerSec / arcsecPerStep;
}

long SKRPicoMount::degreesToSteps(double degrees, double gearRatio, int stepsPerRev, int microsteps)
{
    double stepsPerOutputRev = stepsPerRev * microsteps * gearRatio;
    return (long)lround((degrees / 360.0) * stepsPerOutputRev);
}

// ---------------------------------------------------------------------
// ReadScopeStatus - this firmware has NO encoders, so "status" here is
// really just re-reporting our commanded/integrated position, not a
// true measured one. See README for why this matters and what to do
// about it (a real build wants at least a rough position sanity check
// via plate-solving/sync, not just dead-reckoning forever).
// ---------------------------------------------------------------------
bool SKRPicoMount::ReadScopeStatus()
{
    // TODO: if tracking, currentRA should be advancing with sidereal
    // time between polls. A more complete driver computes elapsed time
    // since last ReadScopeStatus() call and advances currentRA
    // accordingly here, rather than treating it as static during
    // tracking. Left as a stub - see README "Known gaps".

    NewRaDec(currentRA, currentDEC);
    return true;
}
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

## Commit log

2026-08-24 Rename SpaceMount BOM.csv to SpaceMount.csv
    [SpaceMount.csv]
2026-08-25 Upload New CAD
2026-08-26 Update and rename Control/readme.md to controllist.csv
    [controllist.csv]
